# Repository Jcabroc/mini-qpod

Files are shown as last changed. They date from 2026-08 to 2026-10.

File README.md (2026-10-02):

# Mini Q-Pod

Repositorio único del Mini Q-Pod. La rama `main` es el punto de sincronización
entre los equipos de casa y oficina: no se trabaja en copias paralelas ni se
suben binarios generados o respaldos de dispositivos.

## Estado actual

| Componente | Estado | Uso |
|---|---|---|
| `mini_qpod_pico_walk_mvp/` | Activo, pendiente de validación física | Firmware Pico WH para IK y caminata lenta. |
| `mini_qpod_ik_walk_mvp/` | Referencia Nano | Misma lógica compartida; conservar para comparación. |
| `nano_servo_mapping/` | Activo de seguridad | Mapeo/calibración de un servo a la vez. |
| `tools/ik_simulator/` | Activo de ingeniería | IK/FK matemática y validación no física. |
| `tools/ik_walk_simulator/` | Activo de ingeniería | Simulador y paridad con el firmware de caminata. |
| `esp32cam/` | Diagnóstico experimental | Cámara y visión primitiva; no controla servos. |
| `mini_qpod_mvp/` | Referencia MVP | Base anterior, no punto de partida para cambios nuevos. |
| `test_gait*/`, `codigo_control_lite_v1/`, GUI y material CAD | Histórico o soporte | Consultar solo cuando la especificación lo indique. |

La fuente de verdad técnica, hardware, seguridad y estados de validación es
[ESPECIFICACION_TECNICA.md](ESPECIFICACION_TECNICA.md). Las soluciones IK y las
marchas simuladas **no** constituyen una validación física: seguir siempre los
procedimientos de seguridad de cada firmware.

La planificación oficial de la segunda etapa, sus criterios de cierre, evidencia
y sincronización entre equipos está en [docs/ROADMAP.md](docs/ROADMAP.md).
La decisión documentada para la locomoción es
[Pico WH/RP2040](docs/DECISION_LOCOMOCION.md). La ESP32-S3 SuperMini queda
reservada para sensores en una etapa posterior.

## Flujo único de trabajo

1. Actualiza antes de empezar: `git pull --ff-only origin main`.
2. Trabaja en una rama `codex/<tema>` desde `main`.
3. Ejecuta las pruebas relevantes y actualiza la especificación si cambia una
   decisión técnica.
4. Integra el resultado en `main` y vuelve a actualizar el otro equipo.

No se guardan imágenes crudas de firmware, puertos COM locales, cachés Python,
ni productos de compilación. Los respaldos privados de dispositivos se
conservan fuera del repositorio.

## Verificación sin hardware

```powershell
python -B -m unittest discover -s tools/ik_simulator -p 'test_*.py' -v
python -m unittest tools.ik_walk_simulator.test_walk tools.ik_walk_simulator.test_parity -v
python -B -m unittest discover -s tools/servo_calibrator/tests -p 'test_*.py' -v
```

Consulta los README dentro de cada componente para las dependencias y las
instrucciones de compilación.

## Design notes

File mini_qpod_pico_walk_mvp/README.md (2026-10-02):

# Mini Q-POD Pico WH Locomotion MVP

Implementación de locomoción para la Raspberry Pi Pico WH / RP2040 identificada
por serigrafía. Reutiliza una
sola biblioteca local: `libraries/MiniQpodWalkCore/`. Allí viven IK, geometría,
calibración, presets, límites y protocolo Control Lite, compartidos con el
sketch Nano de referencia. Este firmware no se ha cargado ni probado con robot.

Compilar sin cargar:

```powershell
arduino-cli compile --libraries libraries --fqbn rp2040:rp2040:rpipicow mini_qpod_pico_walk_mvp
```

La Pico inicializa el PCA9685 y el NRF24, pero arranca con los 16 PWM apagados.
READY es la única entrada que puede comenzar a escribir canales de patas;
`X` apaga de inmediato, y la pérdida de radio hace que la marcha termine en
apoyo. Los límites y los rechazos IK no se recortan ni se amplían.

GP8/GP9 quedan reservados para una UART futura con ESP32-S3 SuperMini; no se
inicializan ni implementan funciones de S3 en este firmware.

El cableado, requisitos de 3,3 V y procedimiento de banco están en
[docs/PICO_W_LOCOMOTION_BENCH.md](../docs/PICO_W_LOCOMOTION_BENCH.md).

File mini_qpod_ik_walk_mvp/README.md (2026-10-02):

# Firmware Mini Q-POD

Firmware listo para Nano ATmega328P, PCA9685 `0x40`/50 Hz y NRF24. Preserva la
geometría, montaje, calibración y límites revisados en
`328ab9302e3c5cc44ba9fedc3c6c22492ea84f03`. La marcha por cuadro está en
`ik_walk_core.h` y es la misma rutina invocada por Python.

Compila sin cargar para Nano con bootloader antiguo:

```powershell
arduino-cli compile --libraries libraries --fqbn arduino:avr:nano:cpu=atmega328old mini_qpod_ik_walk_mvp
```

El HEX ya compilado para esa placa queda en
`mini_qpod_ik_walk_mvp/build/mini_qpod_ik_walk_mvp.ino.hex`. La compilación no
lo carga al Nano.

Requiere Adafruit PWM Servo Driver y RF24. Al iniciar, todos los canales PWM
quedan apagados y CH12 (cuello) permanece apagado. READY habilita PWM en los
12 canales de patas. Los movimientos fuera de IK o de los límites calibrados
se rechazan; ante un rechazo de marcha se apaga PWM y se informa el error.

## Marcha

WALK es el preset inicial de Caminata lenta y WAVE es Onda. Ambos usan zancada
18 mm, elevación 12 mm, periodo 4 s para WALK / 2,4 s para WAVE, apoyo 0,85 y
desfases `[0, 0.5, 0.75, 0.25]`. Cada vuelo dura 15% del ciclo y el intervalo
entre vuelos 10%: hay como máximo una pata en vuelo y cuatro apoyos durante la
preparación del siguiente trípode. La rutina traslada primero el COM estimado
hacia el polígono de las tres patas que quedarán apoyadas. Conserva los puntos
de apoyo en coordenadas del suelo y usa curvas suaves para levantar, avanzar y
aterrizar.

En la primera vuelta el robot se centra sobre el primer trípode (en el modelo,
unos 9 mm de desplazamiento longitudinal y lateral); las vueltas posteriores
avanzan cerca de los 18 mm nominales por ciclo recto. El ajuste de COM deja un
margen geométrico de 2 mm al final de cada cuadro corregido en el modelo. Es
una aproximación estática, no una simulación de fuerzas ni una validación de
estabilidad física.

TROT permanece experimental. Cuando vuelan dos patas en diagonal, no se
declara estable con solo dos apoyos. PACE está fuera del selector y de los
presets del Nano.

Avance/retroceso y giro se mezclan desde los dos ejes del stick; se suavizan
aceleración, dirección y parada. Al centrar el stick, pulsar CIRCLE o mandar
`STOP`/`PAUSE`, el Nano termina el cuadro de marcha hasta que las cuatro patas
estén apoyadas. `SELECT` o `X` hacen apagado PWM inmediato. `START`/`READY`
solicitan READY; si la marcha está activa espera a detenerse antes de volver a
READY.

Con READY terminado, `STEP 0` a `STEP 3` realiza un vuelo individual coordinado
de L1, R1, L2 o R2. Usa la marcha compartida, prepara el COM sobre las otras
tres patas, detiene el avance al iniciar el vuelo y conserva sus apoyos. Se
puede ejecutar por USB serial; no es un movimiento solo de la interfaz.

La altura corporal cambia suavemente manteniendo los pies de apoyo fijos en el
suelo. La apertura se aplica progresivamente en cada aterrizaje; no reinicia
la fase ni arrastra las patas plantadas. Control Lite: TRIANGLE/CROSS cambian
altura objetivo ±4 mm; SQUARE/R3 cambian apertura objetivo ±3 mm. Los comandos
USB `HEIGHT mm` (−12..12) y `OPENING mm` (0..12) permiten ajustar los mismos
objetivos durante la marcha. Valores fuera de rango se rechazan, nunca se
recortan. Altura y apertura cambian el objetivo IK y pueden parar la marcha si
una articulación llega a un límite configurado.

## Transferir presets y Control Lite

`gait_presets.h` se genera desde
`tools/ik_walk_simulator/gait_defaults.json` con:

```powershell
python -m tools.ik_walk_simulator.export_firmware_presets
```

Tras exportar, vuelve a compilar. La interfaz muestra por separado zancada
nominal, recorrido mundial del pie y avance corporal medido. No amplíes los
límites para forzar recorrido. Por ejemplo, la configuración anterior de
50 mm pedía R1/CH3 a ~94,97° con mínimo 95° y se detenía sin recortar.

El receptor coincide con `codigo_control_lite_v1`: paquete binario PS2J de 9
bytes, canal 76, 250 kbps, dirección `JR001` y payload fijo RF24 de 32 bytes.
El emisor escribe 9 bytes; la radio rellena el tamaño fijo y `RF24::read`
consume el resto al copiar los 9 campos. No usa comandos de texto por radio ni
payload dinámico. Solo el modo 3 posiciones `mode3=2` habilita los ejes.
El transmisor filtra y centra el stick, y el receptor aplica zona muerta 0,18
sin descartar combinaciones de avance y giro. El failsafe de 500 ms al perder
paquetes centra gradualmente ambos ejes y finaliza en apoyo.

## Prueba suspendida futura

No se ha abierto ningún puerto, cargado firmware ni enviado movimiento.
Para una prueba posterior, asegura el cuerpo a un soporte rígido con patas
libres, deja a mano la desconexión de alimentación y revisa juntas/cableado sin
energía. Compila con `atmega328old`, enciende sin iniciar marcha y solicita
READY de forma deliberada. Prueba WALK primero con una entrada breve; observa
que no se solapen vuelos y que no aparezcan errores IK/límite. Verifica CIRCLE
como parada gradual y SELECT como apagado PWM. Repite WAVE; ensaya retroceso y
altura/apertura en incrementos pequeños porque los límites de R1/CH3 siguen
vigentes. Desenergiza antes de tocar el mecanismo. La estimación COM no valida
el contacto dinámico ni sustituye esta comprobación suspendida.

La paridad ejecutable es:

```powershell
python -m unittest tools.ik_walk_simulator.test_walk tools.ik_walk_simulator.test_parity -v
```

Compara objetivos READY, ángulos mecánicos/comandos eléctricos, ciclos completos
cuadro a cuadro, cambios de dirección, altura/apertura, apoyos, avance, COM y
paquete Control Lite.

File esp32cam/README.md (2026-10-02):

# ESP32-CAM USB camera diagnostic

Hardware: ESP32-D0WD-V3 rev 3.1, 4 MB flash, ESP32-CAM-MB CH340,
OV2640 camera using the AI Thinker pin mapping.

Windows serial port: COM25. Working CH340 driver: 3.7.2022.1.

Build with `./build-test.ps1`. ESP-IDF 5.4.4 is installed at
`C:/Espressif/v5.4.4/esp-idf`. Sources are copied to an ASCII-only path
because the installed Kconfig tooling mishandles the accented user path.
Camera driver commit: ee087821fb6da4dc9f294747e61c936a7169c9a7.

The test initializes PSRAM and OV2640, warms up exposure, then sends a VGA
JPEG as hexadecimal text every five seconds over the 115200-baud UART.
It does not configure Wi-Fi. Run `capture.py` using the Espressif Python
environment to save one frame under `results/`.

The original firmware backup is deliberately **not** part of this repository:
raw device images can contain saved configuration. Keep it in a private local
location after a successful read, and restore only from that private copy.
Test binaries are under `firmware/`.

Flash test (after a successful backup), with `python -m esptool`:

```
--port COM25 --baud 115200 write_flash --flash_mode dio --flash_freq 40m --flash_size 4MB 0x1000 firmware/bootloader.bin 0x8000 firmware/partition-table.bin 0x10000 firmware/cam_usb_test.bin
```

Restore an original only from its private local location with
`python -m esptool --port COM25 --baud 115200 write_flash 0 RUTA_PRIVADA_AL_RESPALDO.bin`.

Validated on 2026-09-22: full original backup verified by device MD5; test flash verified; PSRAM 8388608 bytes; OV2640 PID 0x26 initialized successfully; captured and visually inspected a 640x480 JPEG in results/camera.jpg.

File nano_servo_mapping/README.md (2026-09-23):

# Mini Q-POD Servo Mapping 1.0.0

Firmware independiente para medir el mapeo eléctrico → mecánico, sin IK,
movimientos colectivos, balance ni acceso a EEPROM. No sustituye ni modifica
`mini_qpod_mvp`. No se ha cargado ni probado físicamente.

## Cableado revisado antes de implementar

Según `mini_qpod_mvp/robot_config.h`, `gait_balance.h` y
`mini_qpod_pico_imu/mini_qpod_pico_imu.ino`:

| Función | Nano | Conexión |
|---|---|---|
| Host 115200 baud | UART USB D0/D1 | USB; no conectar la Pico aquí |
| IMU 38400 baud | D2 RX SoftwareSerial | Pico GP4 TX y GND común |
| TX ficticio SoftwareSerial | D8 | **Sin conexión física** |
| PCA9685 dirección 0x40 | A4 SDA / A5 SCL | I²C, lógica y GND común |
| LED | D5 | Encendido al enviar PWM individual |
| Buzzer | D4 | LOW, sin tonos |

No usar D3 → GP5 directamente: 5 V del Nano no son adecuados para la Pico.
Esta revisión verifica el pinout registrado, no el cableado físico presente.
No se añade un pin OE: no consta una conexión existente. La alimentación de
servos debe poder desconectarse físicamente, también durante reset/carga.
Mejora futura obligatoria: conectar `OE` del PCA9685 a un GPIO del Nano con
pull-up, de forma que las salidas permanezcan deshabilitadas durante arranque,
reinicio o fallo del Nano.

## Configuración RAM y significado de los ángulos

La siguiente tabla reproduce el `CONFIG` activo comunicado por el usuario,
no los defaults compilados del MVP ni una lectura nueva de EEPROM.
Margen global 5°; extremos seguros inclusivos.

| CH | Articulación | Mín / centro / máx eléctricos | Dirección histórica | Intervalo con margen |
|---|---|---|---|---|
| 0 | L1 COXA | 20 / 90 / 115 | +1 | 25–110 |
| 1 | L1 FÉMUR | 10 / 110 / 180 | +1 | 15–175 |
| 2 | L1 TIBIA | 25 / 90 / 180 | −1 | 30–175 |
| 3 | R1 COXA | 90 / 110 / 180 | +1 | 95–175 |
| 4 | R1 FÉMUR | 10 / 90 / 180 | −1 | 15–175 |
| 5 | R1 TIBIA | 0 / 90 / 170 | −1 | 5–165 |
| 6 | L2 COXA | 70 / 100 / 180 | +1 | 75–175 |
| 7 | L2 FÉMUR | 10 / 90 / 180 | +1 | 15–175 |
| 8 | L2 TIBIA | 0 / 100 / 160 | −1 | 5–155 |
| 9 | R2 COXA | 30 / 100 / 140 | −1 | 35–135 |
| 10 | R2 FÉMUR | 10 / 105 / 175 | −1 | 15–170 |
| 11 | R2 TIBIA | 40 / 115 / 180 | −1 | 45–175 |
| 12 | Cuello | 75 / 95 / 120 | +1 | 80–115 |

`ARM`/`MOVE` reciben grados **eléctricos absolutos**. No aplican dirección,
offset ni centro a la entrada: las direcciones se conservan como evidencia,
pendiente su correspondencia con las convenciones IK. Los intervalos con margen
son límites de software heredados, no una certificación de ausencia de colisiones.

Los centros físicos históricos CH0–CH11 son, por separado:
1505, 1700, 1590, 1645, 1555, 1635, 1690, 1635, 1565, 1590, 1600, 1725 µs.
No se convierten en centros eléctricos nuevos. La READY histórica (COXA
L1 −6°, R1 −8°, L2 +8°, R2 +6°, fémures 0°, tibias −10°) tiene una convención
todavía sin reconciliar con la IK y no se implementa aquí.

Conversión explícita, compatible con el redondeo y mapa del código MVP local:

```
a = trunc(deg + 0.5)                         # entradas válidas positivas
cuentas = 110 + trunc(a * 400 / 180)        # entero largo, no clamp
us_nominal = cuentas * (prescale + 1) / 25  # oscilador nominal 25 MHz
```

Se configura 50 Hz; se informa el prescaler leído del dispositivo, normalmente
121. Con él, 90° → 310 cuentas → 1512.80 µs nominales. No es una medición
del oscilador ni del pulso real. La rampa interna es de 10°/s, pasos máximos
0.2° cada 20 ms; la salida se cuantiza a grados enteros y cuentas. No se
promete velocidad física exacta del eje. Un bucle retrasado no recupera tiempo
con un salto grande. No se calcula trigonometría ni se duplica la IK.

## Protocolo

ASCII, mayúsculas, 115200 baud, líneas terminadas en LF (CRLF admitido).
Máximo 79 caracteres; líneas largas o corruptas se descartan completas.
Decimales con punto, sin exponentes, NaN ni infinito; número exacto de argumentos.
`X` es además un byte de emergencia inmediato, aun dentro de una línea incompleta.
No enviar varios comandos de movimiento en lote.

| Orden | Efecto |
|---|---|
| HELP | Enumera exclusivamente este protocolo y códigos |
| STATUS | Estado PWM, selección, canal activo, objetivo/salida, IMU, watchdog, último aborto |
| CONFIG | Tabla RAM con centro, conversión nominal, dirección y margen |
| IMU | Frescura, roll/pitch, edad y umbrales |
| SELECT ch | Apaga los 13 canales y selecciona uno; **no envía PWM activo** |
| ARM ch deg | Primera activación explícita: exige selección, IMU saludable y rango seguro |
| MOVE ch deg | Cambia el objetivo del único canal ya armado; rampa 10°/s |
| PING | Renueva heartbeat; nunca activa ni mueve |
| OFF | FULL_OFF en los 13 canales, elimina selección y armado |
| X | Igual apagado; no necesita LF |

`ARM` repetido se rechaza. `MOVE` antes de `ARM` se rechaza. Errores de sintaxis,
canal o rango conservan el objetivo y la salida anteriores, salvo que venza una
protección independiente: entonces se apaga. No hay recorte silencioso.
Después de OFF/aborto se requieren nueva selección y nuevo ARM; PING no rearma.

Cada respuesta tiene un sobre:
`REPLY cmd=... ch=... result=... accepted=... counts=... us_nominal=...`.
`ch=-1` y `NA` significan que no existe canal/ángulo aplicable; en un rechazo
`accepted=NA` significa que no se aceptó ningún ángulo nuevo. STATUS identifica
la salida conservada. CONFIG y STATUS/IMU/HELP añaden líneas de detalle al sobre.
CONFIG informa centros de referencia, **no** una aceptación para energizarlos.
El arranque emite nombre, versión y `build=local-fecha-hora` de compilación.

Resultados: 0 OK; 1 sintaxis; 2 canal; 3 no seleccionado; 4 ya armado;
5 no armado; 6 rango; 7 IMU; 8 bus I²C.
Abortos: 0 ninguno; 1 pérdida IMU; 2 inclinación; 3 watchdog host; 4 bus I²C.
La causa del último aborto se conserva incluso tras OFF o un nuevo ARM.
El fallo de bus queda bloqueado hasta reinicio; consultas y OFF siguen disponibles.

## Protecciones y límites de esta fase

Al arrancar se solicita FULL_OFF en los 13 canales antes y después de configurar
la frecuencia. SELECT también apaga todos; ARM vuelve a hacerlo antes del primer
pulso individual. Los canales restantes no sostienen ninguna postura.

IMU: `IMU,secuencia,roll,pitch*XX`, XOR hexadecimal del texto anterior al asterisco.
Solo tramas completas con checksum correcto, valores finitos y secuencia distinta
renuevan frescura. Se admite vuelta del contador de 16 bits; duplicados no renuevan.
Se ignora telemetría SENSOR. Edad **menor de 250 ms** y roll/pitch dentro de
±12° son obligatorios. A 250 ms sin trama o inclinación excesiva: apagado.
El watchdog de host apaga a **1000 ms** desde ARM o el último PING; MOVE y las
consultas no lo renuevan. El host debe enviar PING cada 200 ms mientras esté armado.
Las comparaciones de tiempo admiten el desbordamiento de millis().

No hay esperas de movimiento; las UART se atienden con lotes limitados. Apagado
significa envío de FULL_OFF en el mismo servicio de seguridad/comando, sujeto a
latencia UART/I²C. Wire tiene timeout de 3 ms por transacción. No es un circuito
de parada independiente: un bus averiado, MCU bloqueado o PCA que conserve estado
durante un reset puede impedir el apagado físico. Ante fallo I²C se intenta
apagar todo y se bloquea ARM, pero el estado físico no puede certificarse.

**ARM aplica inmediatamente el ángulo eléctrico solicitado.** Sin realimentación
de posición no existe punto inicial conocido para una rampa desde reposo. Suspender
el robot no elimina choques entre piezas. Confirmar físicamente un ángulo inicial
antes de ARM, disponer de corte de alimentación y no recorrer extremos a ciegas.
La rampa conservadora solo se aplica a MOVE después del primer pulso.

## Compilar y probar sin hardware

Dependencias: Arduino AVR Boards 1.8.6, Adafruit PWM Servo Driver Library 3.0.2
y Adafruit BusIO. Host: Python y `ziglang` (validado con 0.16.0).

```powershell
python -m pip install ziglang
& ./nano_servo_mapping/tests/run.ps1
arduino-cli compile --fqbn arduino:avr:nano:cpu=atmega328old nano_servo_mapping
python -B -m unittest discover -s tools/ik_simulator -p 'test_*.py' -v
python -B -m unittest discover -s tools/ik_pose_lab -p 'test_*.py' -v
python -B -m unittest discover -s tools/servo_calibrator/tests -p 'test_*.py' -v
python -B -m unittest discover -s esp32cam/tools/primitive-vision-monitor -p 'test_*.py' -v
git diff --check
```

Las pruebas C++ ejecutan el mismo parser, recepción IMU, límites y controlador
usado en AVR con un PCA simulado; no abren puertos. El ejecutable temporal se
crea fuera del repositorio. No prueban señales, cableado ni latencia física.

## Procedimiento futuro de carga y primera medición (no ejecutado)

1. Cortar físicamente la fuente de servos; robot suspendido y articulaciones
   apoyadas para que los doce canales apagados no provoquen una caída.
   Verificar el pinout anterior, masas, orientación IMU y corte accesible.
2. Tras revisar y autorizar esta versión, compilar y cargar por bootloader USB
   **solo el sketch nano_servo_mapping**, con placa Nano / ATmega328P Old Bootloader.
   Comando de referencia, sustituyendo el puerto confirmado:
   `arduino-cli upload -p COM_CONFIRMADO --fqbn arduino:avr:nano:cpu=atmega328old nano_servo_mapping`.
   No usar programador ISP, borrado de chip ni modificar fuses. Este sketch no
   incluye EEPROM.h ni accede a EEPROM. La conservación al cargar depende también
   del método de carga; el procedimiento usa bootloader, no borrado por ISP.
3. Con potencia aún desconectada, abrir 115200, verificar nombre/versión/build,
   HELP/CONFIG/STATUS/IMU. Debe indicar OFF, selected=-1, energized=-1,
   sin FATAL; verificar IMU saludable repetidamente. No continuar si falla.
4. Iniciar heartbeat PING cada 200 ms con un host que no envíe nada más
   automáticamente. El calibrador antiguo no se presume compatible con este protocolo.
   Enviar SELECT 0 y comprobar OFF y selected=0. Con instrumentos, confirmar que
   los otros doce canales carecen de pulsos antes de alimentar servos. Detenerse aquí
   y solicitar autorización explícita antes de enviar cualquier `ARM`.
5. Para CH0, 90° es el centro eléctrico registrado, no un centro mecánico aprobado.
   Confirmar que es una primera posición físicamente admisible; si no puede
   asegurarse, desacoplar la carga mecánica y establecer una referencia antes de
   energizar. Solo entonces conectar potencia y enviar ARM 0 90 explícitamente.
   Comparar respuesta (310 cuentas, µs según prescaler) y STATUS; verificar que
   solo CH0 está energizado. Cortar potencia ante cualquier anomalía.
6. Registrar yaw mecánico respecto de la referencia radial nominal de L1
   (+135° global, +X derecha, +Y frontal), junto a grados eléctricos, cuentas,
   pulso medido si disponible y sentido observado. No asumir que dirección +1
   prueba el signo de IK. Con espacio comprobado, MOVE 0 91, esperar llegada
   manteniendo PING, medir; MOVE 0 90 y medir retorno. OFF y verificar apagado.
   La dirección opuesta solo tras comprobar separación física. No buscar topes.
7. Antes de ampliar mediciones, comprobar corte por ausencia de PING, pérdida de
   IMU y OFF/X con carga desacoplada o potencia desconectada e instrumento sobre
   PWM. Comprobar todos los canales inactivos tras cada aborto. No inclinar el
   robot suspendido con servos cargados para ensayar el umbral.
8. CH1 y CH2 requieren referencias de fémur horizontal y ángulo relativo de
   tibia, medidas individualmente mediante SELECT y nuevo ARM. No energizar la
   pata completa. Guardar mediciones externamente; este firmware no las persiste.

El resultado pendiente es una tabla medida por canal que permita reconciliar
centro, offset y signo con la IK; no se implementa aún ese puente ni una marcha.

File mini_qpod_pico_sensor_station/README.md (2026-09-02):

# Mini Q-POD Pico Sensor Station

Firmware para **Raspberry Pi Pico W** que publica los sensores en el USB serie a
115200 baud para la aplicación `Mini-QPOD-Sensor-Station.exe`; conserva además
la trama IMU y retransmite todos los sensores hacia el Nano por GP4 → D2 a
38400 baud. El MVP actualizado del Nano reenvía estas tramas por su USB a
115200 baud.

## Pinout

| Periférico | Pico W |
|---|---|
| MPU6050 SDA / SCL | GP0 / GP1 |
| Sonar HC-SR04 TRIG / ECHO | GP2 / GP3 |
| DHT | GP6 |
| Impacto | GP7 |
| Touch | GP9 |
| Mini PIR | GP10 |
| LDR izquierda / derecha | GP26 ADC0 / GP27 ADC1 |
| RGB | GP13 / GP14 / GP15 — reservado, no se activa |

## Seguridad y carga

1. El ECHO del HC-SR04 **debe** pasar por divisor 5 V → 3.3 V antes de GP3.
2. El firmware inicia intentando DHT11 y alterna automáticamente DHT11/DHT22
   si no obtiene respuesta. Cuando detecte uno, lo informa por USB. Si no
   detecta ninguno, revise alimentación, GND, cable DATA y el pull-up.
3. El módulo de impacto conectado fue observado activo en alto en reposo, por
   eso `IMPACT_ACTIVE_LOW` está en `true`. Si una prueba física demuestra lo
   contrario, vuelva a cambiarlo.
4. Este sketch no controla el RGB ni el buzzer: el tipo de LED aún no está
   confirmado y el buzzer pertenece al Nano D4.
5. Conecte la aplicación al **COM USB de la Pico**, no al Nano, para ver todos
   estos datos. El Nano MVP actual solo recibe la IMU.

Compile con:

```powershell
arduino-cli compile --fqbn rp2040:rp2040:rpipicow .
```

La telemetría usa líneas `SENSOR,<sensor>,<valor>`; por ejemplo
`SENSOR,dht,23.4,58.0` y `SENSOR,ldr,512,490`.

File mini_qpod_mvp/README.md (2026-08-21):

# Mini Q-Pod MVP

Firmware mínimo, estructurado y seguro para calibrar los 13 servos del Mini
Q-Pod, probar cada pata y ejecutar una primera marcha lenta. Este MVP no incluye
cinemática inversa.

La fuente de verdad técnica del robot es
[`../ESPECIFICACION_TECNICA.md`](../ESPECIFICACION_TECNICA.md). Este README explica
el uso práctico; cualquier cambio de hardware, límites, protocolo, seguridad o
arquitectura también debe registrarse en la especificación técnica.

> **Advertencia:** los límites iniciales provienen del proyecto anterior y no
> sustituyen una calibración física. Las primeras pruebas deben hacerse con el
> robot elevado, sin peso sobre las patas y con acceso inmediato a la energía.

## Archivos

- `mini_qpod_mvp.ino`: programa principal, consola y modos.
- `robot_config.h`: único archivo de configuración habitual.
- `servo_control.h`: límites, EEPROM, movimiento suave y PCA9685.
- `gait_balance.h`: postura, marcha y receptor UART de orientación desde la Pico.
- `../mini_qpod_pico_imu/mini_qpod_pico_imu.ino`: lectura de la MPU6050 en la Pico W.

Toda orden termina en `ServoController`, que recorta ángulos al rango seguro y
limita la velocidad antes de escribir en el PCA9685.

## Hardware y dependencias

- Arduino Nano o compatible (el firmware parte del hardware actual).
- PCA9685 en dirección I²C `0x40`.
- 13 servos en canales 0 a 12.
- Biblioteca Arduino `Adafruit PWM Servo Driver Library`.
- `Wire` y `EEPROM`, incluidas con el core de Arduino AVR.
- Raspberry Pi Pico W conectada por UART al Nano.
- MPU6050 en `0x68`, conectada por I2C a la Pico W.

La fuente de los servos debe ser externa, adecuada a su consumo y compartir GND
con Arduino. No alimente los 13 servos desde el pin de 5 V del Nano.

## Instalación

1. Abra `mini_qpod_mvp/mini_qpod_mvp.ino` en Arduino IDE.
2. Instale **Adafruit PWM Servo Driver Library** desde el gestor de bibliotecas.
3. Seleccione la placa y el procesador correctos del Nano.
4. Revise `robot_config.h`, especialmente canales y límites iniciales.
5. Compile y cargue el sketch.
6. Abra Monitor Serial a **115200 baud**, terminación “Nueva línea”.

El arranque siempre deja los servos apagados. Escriba `HELP` para ver comandos.

## Secuencia obligatoria de puesta en marcha

### 1. Inspección sin energía de servos

- Confirme canal y articulación de cada servo.
- Confirme que las patas pueden moverse sin cables atrapados.
- Eleve el robot para que ninguna pata soporte peso.
- Tenga preparada la desconexión de la fuente de servos.

### 2. Entrada segura a calibración

Antes de alimentar los servos, compruebe que `IMU` informa `healthy=1`. Ejecute:

```text
CALIB
```

`CALIB` entra al modo de calibración con todos los PWM apagados. Después elija
explícitamente un canal; `SELECT` apaga primero cualquier canal que estuviera
habilitado y no produce PWM:

```text
SELECT 0
```

Solo `ENABLE` escribe el primer PWM, por lo que puede mover el servo de inmediato
desde su posición sin energía. Indique un ángulo inicial deliberado y mantenga
acceso a `OFF` y al corte de fuente:

```text
ENABLE 0 90
```

Durante calibración se habilita como máximo un canal. La pérdida de IMU aborta y
apaga los PWM. Por defecto, una inclinación mayor a 12° también aborta incluso si
el robot está elevado; `CALIBRATION_ABORT_ON_TILT` en `robot_config.h` documenta
y hace configurable esa política.

Con un canal habilitado, la aplicación debe enviar `PING` válido al menos cada
segundo. El calibrador provisional lo hace cada 250 ms. Si transcurre más de
`CALIBRATION_HOST_TIMEOUT_MS` (1000 ms) sin `PING` ni un comando válido de
calibración, el Nano apaga todos los PWM, limpia el canal seleccionado y vuelve a
`SAFE_OFF` con `[ABORT] HOST_TIMEOUT`. Un nuevo enlace nunca reactiva servos:
requiere otra vez `CALIB`, `SELECT` y `ENABLE`.

### 3. Calibración de cada servo

Mueva un servo a la vez con incrementos pequeños:

```text
SERVO 0 88
CENTER 0
```

Después de encontrar valores seguros, registre mínimo, centro y máximo:

```text
LIMITS 0 50 90 150
```

La condición obligatoria es `min < center < max`. El firmware añade un margen
interno de 5 grados a cada extremo. Repita para los canales 0 a 12 y revise:

```text
CONFIG
```

`LIMITS` exige que el PWM esté apagado. Ejecute `SELECT` (que apaga el canal),
ajuste los valores y vuelva a habilitar explícitamente el canal para probarlos.
Guarde solamente después de probar todos los canales y apagar los PWM:

```text
OFF
SAVE
```

`LOAD` recupera EEPROM únicamente en `OFF`. `DEFAULTS`, permitido solo en `OFF`, recupera los valores
compilados en `robot_config.h`; después hay que probarlos antes de ejecutar
`SAVE`.

### 4. Postura de pie

Apoye el robot en una superficie despejada y antideslizante:

```text
STAND
```

Verifique que ninguna articulación sature o fuerce la estructura. Si la postura
no es correcta, use `OFF`, vuelva a calibración y ajuste los límites o los valores
`DEFAULT_STAND_*` en `robot_config.h`.

### 5. Prueba individual de patas

Desde `STAND`, pruebe una sola pata y espere a que termine:

```text
LEG 0
LEG 1
LEG 2
LEG 3
```

Orden de nombres: `0=L1`, `1=R1`, `2=L2`, `3=R2`. Cada prueba desplaza primero
el cuerpo, levanta la pata, la adelanta, la baja y vuelve a postura estable.

No continúe si el cuerpo vuelca, una pata se arrastra, un servo alcanza el choque
o la fuente se reinicia.

### 6. Primera marcha

Solo después de superar las cuatro pruebas:

```text
STAND
UNLOCK_WALK
WALK
```

`UNLOCK_WALK` dura hasta reiniciar. La marcha usa el orden L1, R2, R1, L2 y una
sola pata elevada. Para detenerla:

```text
OFF
```

## IMU y balance

La MPU6050 no se conecta al Nano. La Pico W la lee por I2C, calcula roll/pitch
y envía una trama cada 20 ms al Nano. El cableado registrado es:

| Señal | Pico W | Nano |
|---|---:|---:|
| I2C SDA MPU6050 | GP0 | -- |
| I2C SCL MPU6050 | GP1 | -- |
| UART Pico TX -> Nano RX | GP4 | D2 |
| UART Nano TX -> Pico RX | GP5 | D3 (desconectar en este MVP) |
| Referencia eléctrica | GND | GND |

Ambos firmwares usan UART a 38400 baud. El formato es
`IMU,<secuencia>,<roll>,<pitch>*<CRC>`, donde CRC es el XOR de los bytes previos
al asterisco. Cargue primero `mini_qpod_pico_imu.ino` en la Pico y luego el MVP
en el Nano. Con el robot inmóvil y nivelado, ejecute `IMU` e incline manualmente
el cuerpo para comprobar ejes y signos antes de probar las patas.

La conexión usada por este MVP es unidireccional: GP4 de la Pico (3.3 V) puede
entrar a D2 del Nano. No conecte D3 del Nano directamente a GP5: la salida de 5 V
del Nano requiere adaptación de nivel antes de entrar a la Pico. El firmware del
Nano deja esa transmisión deshabilitada.

Con la IMU activa, una lectura inválida o inclinación superior a 12 grados aborta
el movimiento. También aborta si el Nano no recibe una trama válida durante 250
ms. La corrección de balance está limitada a 4 grados y también pasa por los
límites mecánicos.

La IMU estima inclinación; no mide directamente el centro de gravedad. El ajuste
real del soporte se realiza mediante `DEFAULT_BODY_SHIFT_GAIN` y debe validarse
físicamente para cada pata.

## Parámetros que se pueden ajustar

Mantenga pocos cambios por prueba:

- `DEFAULT_SERVOS`: límites y centros físicos.
- `DEFAULT_SAFETY_MARGIN_DEG`: margen contra choque.
- `DEFAULT_MAX_SPEED_DEG_S`: velocidad máxima.
- `DEFAULT_STAND_COXA_GAIN` y `DEFAULT_STAND_HEIGHT_GAIN`: postura.
- `DEFAULT_STEP_GAIN`: longitud articular del paso.
- `DEFAULT_LIFT_GAIN`: elevación.
- `DEFAULT_BODY_SHIFT_GAIN`: traslado previo del cuerpo.
- Tiempos `DEFAULT_*_MS`: duración de cada fase.
- Parámetros `DEFAULT_*TILT*` y `DEFAULT_BALANCE_*`: seguridad de IMU.

Cambiar los valores compilados no reemplaza automáticamente una configuración ya
guardada en EEPROM. Use `OFF`, `DEFAULTS`, repita las pruebas y finalmente `SAVE`.

## Criterio de aprobación del MVP

El firmware puede considerarse listo para continuar cuando:

1. Los 13 canales están identificados y calibrados.
2. Reiniciar conserva una configuración válida.
3. `CENTER` y `STAND` no producen choques.
4. Cada `LEG 0..3` completa diez ciclos sin pérdida de estabilidad.
5. `OFF` detiene cualquier prueba.
6. Con IMU activa, inclinación excesiva detiene la prueba.
7. La marcha completa varios ciclos lentos sin alcanzar límites.

El paso siguiente será corregir la geometría del desplazamiento de cuerpo usando
las medidas reales del robot y, una vez estable, introducir cinemática inversa.

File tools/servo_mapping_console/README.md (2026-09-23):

# Consola Mini Q-POD Servo Mapping

Cliente mínimo para el firmware `nano_servo_mapping`. Usa `pyserial`, siempre
envía líneas terminadas en LF y mantiene `PING` cada 250 ms mediante un bloqueo
de escritura compartido. El registro se guarda por defecto en
`local_backups/servo_mapping_console.log`, fuera del control de versiones.

```powershell
python -m pip install pyserial
python tools/servo_mapping_console/console.py --port COM9 --baud 115200
```

Al conectar espera el arranque y consulta `STATUS`, `IMU` y `CONFIG`. Solo
acepta `HELP`, `STATUS`, `CONFIG`, `IMU`, `SELECT`, `ARM`, `MOVE`, `OFF` y `X`.
`X` es el apagado de emergencia; también se envía al cerrar, con Ctrl+C, ante
una excepción serial y cuando la IMU deja de estar saludable. No incluye EEPROM,
WALK, STAND, límites ni expansión.

En esta fase la consola solo permite confirmar `ARM 0 90`; exige confirmación
mostrando rango seguro, cuentas y microsegundos nominales. Después limita
`MOVE 0` a 89–91°. No reintenta ARM ni MOVE.

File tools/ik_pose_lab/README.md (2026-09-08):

# Mini Q-POD Pose Lab

Aplicación de escritorio de simulación, Python 3.10+ con Tkinter (incluido en
el instalador estándar de Python para Windows). Desde la raíz del repositorio:

```powershell
python -B -m tools.ik_pose_lab
```

También se puede ejecutar `python tools/ik_pose_lab/launch.py`.
Tres paneles simultáneos muestran superior X/Y, frontal X/Z y el plano radial
de la pata seleccionada. Cuerpo de 93 × 93 mm, colores azul/verde/violeta para
COXA/fémur/tibia, objetivos ámbar o rojos. Las proyecciones se ajustan al rango.
La altura es la distancia del origen al plano de pies Z=-altura; cuerpo siempre
nivelado (roll/pitch=0). La vista frontal superpone las patas delanteras/traseras.

Los campos numéricos recalculan al editar. Apertura es la componente lateral
nominal desde cada montaje cuando yaw=0: radio = sqrt(2)*apertura.
Avance desplaza todos los pies en +Y después del abanico simétrico COXA.
Yaw positivo abre el abanico hacia los laterales desde X_NEUTRAL; no es un
ángulo eléctrico. Tras añadir avance, el yaw resuelto puede diferir del abanico.
Rama de rodilla: -1 o +1. No se imponen límites CAD ni eléctricos.

READY (altura 80, apertura 75) y X_NEUTRAL (70,85) son ejemplos matemáticos
editables, no posturas físicas aprobadas ni presets extraídos de las vistas CAD.
Los círculos ámbar marcan regiones cualitativas de incertidumbre alrededor
de COXA, con radio COXA+FEMUR solo para visualización. Sus solapamientos no
son detección de colisión: faltan volúmenes, holguras y trayectorias CAD.

Estado por pata: OK IK acompañado de zona mecánica pendiente, inalcanzable
o singularidad. Nunca se indica aprobación física global. Ver
[restricciones](../../docs/ik_constraints.md).

Guardar escribe un JSON versionado con controles; Cargar acepta ese formato
y también exportaciones. Exportar añade objetivos corporales, ángulos mecánicos
en radianes, comprobaciones y avisos calculados mediante la IK compartida.
Al cargar se recalculan resultados, sin confiar en datos derivados exportados.

Se revisó `gui_qpod_config.py`: se reaprovecha el patrón Tk/ttk y diálogos JSON.
Sus clases mezclan calibración y transporte serial; no se importan porque
introducirían dependencias de hardware innecesarias. La IK no se duplica:
se usa `ik_simulator.validation`, y FK para los extremos; los puntos intermedios
de la cadena son únicamente geometría de dibujo.

## Pruebas

```powershell
python -B -m unittest discover -s tools/ik_simulator -p "test_*.py" -v
python -B -m unittest discover -s tools/ik_pose_lab -p "test_*.py" -v
```

## EXE portable Windows (opcional)

En un entorno de construcción con Python y PyInstaller instalado
(`python -m pip install pyinstaller`), ejecutar:

```powershell
powershell -ExecutionPolicy Bypass -File tools/ik_pose_lab/build_exe.ps1
```

Resultado: `tools/ik_pose_lab/dist/Mini-QPOD-Pose-Lab.exe`. Empaqueta Tcl/Tk
y Python en un único archivo, sin consola. Compilar en Windows para Windows.
No requiere archivos CAD al ejecutar. La construcción no instala paquetes
automáticamente; el EXE debe probarse en el equipo de destino.
No existe comunicación serial, PWM, carga a Arduino ni control físico.

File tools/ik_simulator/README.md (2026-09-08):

# IK matemática en PC

La capa separada `validation.py` ofrece `validate_target(leg, body_point,
knee_sign=-1)`: devuelve solución, estados por comprobación y avisos sin aplicar
límites CAD. Ver [restricciones y referencias CAD](../../docs/ik_constraints.md).
Los estados mecánicos, eléctricos y de colisión permanecen pendientes;
`ik_reachable` no equivale a aprobación física.

Modelo independiente en Python (biblioteca estándar), sin acceso serial ni
dependencias de Arduino. Medidas confirmadas por el usuario desde el STEP original:
chasis de 93.0 × 93.0 mm entre centros COXA; COXA=42.294 mm,
FEMUR=60.611 mm, TIBIA=88.714 mm, todas centro a centro.

Origen del cuerpo: centro geométrico; +X derecha, +Y frontal, +Z arriba.
Se asumen los cuatro ejes COXA en el plano Z=0.

| Pata | X (mm) | Y (mm) | Yaw de montaje |
|---|---:|---:|---:|
| L1 | -46.5 | +46.5 | +135° |
| R1 | +46.5 | +46.5 | +45° |
| L2 | -46.5 | -46.5 | -135° |
| R2 | +46.5 | -46.5 | -45° |

El yaw es **mecánico/radial**, medido desde +X hacia +Y alrededor de +Z.
No es un ángulo eléctrico de servo. En el marco local de cada pata, +X apunta
radialmente hacia fuera, +Y es tangencial y +Z sigue arriba.
El yaw devuelto por IK es relativo al yaw de montaje de esa pata.

La API usa mm y radianes. Femur=0 significa horizontal hacia fuera; su signo
positivo eleva la pata. Knee=0 alinea tibia y fémur; knee es el ángulo relativo
de la tibia respecto del fémur, con el mismo signo de elevación.
Se supone COXA horizontal y articulaciones fémur/tibia coplanares, sin offsets
adicionales. Estas convenciones matemáticas requieren validación antes de hardware.

Para un objetivo local (x,y,z): r=hypot(x,y), h=r-COXA,
cos(knee)=(h²+z²-FEMUR²-TIBIA²)/(2 FEMUR TIBIA),
femur=atan2(z,h)-atan2(TIBIA sin(knee), FEMUR+TIBIA cos(knee)).
Yaw=atan2(y,x). Se elige la orientación COXA hacia el objetivo; no se enumera
la solución alternativa con COXA girada 180° y alcance radial firmado negativo.

`knee_sign=-1` (predeterminado) o `+1` selecciona las dos ramas planares;
ninguna se declara físicamente segura. Se rechazan objetivos fuera del anillo
de alcance y el eje vertical COXA, donde yaw no queda determinado.
Las fronteras totalmente plegada/extendida se aceptan aunque son singulares;
no se calculan velocidades ni Jacobianos. Tolerancia de frontera: 1e-9 mm,
con recorte del coseno únicamente para redondeo numérico.

La conversión a **ángulos eléctricos por canal se hará en una capa posterior**:
centros, signos, offsets, calibración y límites no pertenecen a esta IK.
Alcanzable matemáticamente no implica ausencia de colisiones ni viabilidad física.
No se modifican sketches, EEPROM ni límites de servos.

Desde la raíz del repositorio:

```console
python -B -m unittest discover -s tools/ik_simulator -p "test_*.py" -v
```

Ejemplo en Python:

```python
from tools.ik_simulator.kinematics import inverse, forward
angles = inverse("R1", (120, 120, -80))
print(angles)  # radianes mecánicos
print(forward("R1", angles))  # recupera el objetivo en el marco del cuerpo
```

Las pruebas cubren dimensiones, ejes radiales, una solución analítica,
fronteras, errores y reconstrucción FK(IK(p)) de puntos aleatorios reproducibles
para ambas ramas y las cuatro patas. No constituyen validación física.

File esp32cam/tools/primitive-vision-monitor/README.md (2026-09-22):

# Q-POD Primitive Vision Monitor

Monitor local para Windows de la salida serie de la ESP32-CAM Stage 1. Usa Tkinter y pyserial; el parser está separado de la interfaz para poder cambiar el protocolo después.

## Ejecución

Con el entorno Python de ESP-IDF preparado:

```powershell
Set-Location tools\primitive-vision-monitor
& 'C:\Espressif\tools\python\v5.4.4\venv\Scripts\python.exe' monitor.py
```

Selecciona `COM25` (o el puerto que Windows asigne), `115200` y pulsa `CONNECT`. Al conectar, la herramienta genera un pulso de reset del ESP32-CAM-MB; el estado debe pasar de `WAITING DATA` a `RX OK` y el monitor serie debe mostrar el arranque y las líneas `MOTION`.

Prueba del parser sin hardware:

```powershell
& 'C:\Espressif\tools\python\v5.4.4\venv\Scripts\python.exe' test_parser.py
```

Las líneas desconocidas se conservan en el log, pero no afectan a la interfaz. `APPROACHING`, `RECEDING`, `CONFIDENCE`, `LIGHT` y bounding boxes quedan previstos para futuras líneas del protocolo.

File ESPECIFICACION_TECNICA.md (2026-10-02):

# Especificación técnica oficial — Mini Q-Pod

| Campo | Valor |
|---|---|
| Documento | Especificación técnica y fuente de verdad del robot |
| Proyecto | Mini Q-Pod |
| Repositorio | `https://github.com/Jcabroc/mini-qpod.git` |
| Rama oficial actual | `main` |
| Versión del documento | `0.5.0` |
| Firmware activo en desarrollo | `mini_qpod_pico_walk_mvp/mini_qpod_pico_walk_mvp.ino` |
| Estado | IK y caminata compilables, pendientes de validación física |
| Última actualización | 2026-10-02 |

> Este documento es la fuente de verdad técnica del Mini Q-Pod. Toda decisión
> que cambie hardware, conexiones, límites, seguridad, comportamiento, protocolo,
> dependencias o pruebas debe quedar registrada aquí en el mismo cambio de código.

## 1. Objetivo del sistema

Mini Q-Pod es un robot cuadrúpedo de cuatro patas, tres articulaciones por pata y
un servo adicional para el cuello. El objetivo de la versión actual es conseguir
una plataforma segura y calibrable que:

1. Controle 13 servos mediante PCA9685.
2. Respete límites mecánicos configurables por articulación.
3. Limite la velocidad antes de enviar órdenes físicas.
4. Permita calibrar y guardar parámetros sin reescribir todo el firmware.
5. Adopte una postura base reproducible.
6. Desplace el cuerpo antes de levantar una pata.
7. Pruebe individualmente las cuatro patas.
8. Ejecute una marcha lenta con una sola pata elevada.
9. Incorpore posteriormente estabilización con IMU y cinemática inversa.

La cinemática inversa no pertenece al alcance del MVP actual.

### Modelo matemático independiente en PC (2026-09-08)

`tools/ik_simulator/` contiene la IK/FK y sus pruebas independientes del firmware.
Las medidas confirmadas desde el STEP original son: separación entre centros
COXA de 93.0 mm en ancho y largo; COXA=42.294 mm, FEMUR=60.611 mm y
TIBIA=88.714 mm, centro a centro. Origen en el centro geométrico del cuerpo,
+X derecha, +Y frontal, +Z arriba; montaje COXA en Z=0 como supuesto del modelo.
Montajes (X mm, Y mm, yaw): L1=(-46.5,+46.5,+135°),
R1=(+46.5,+46.5,+45°), L2=(-46.5,-46.5,-135°), R2=(+46.5,-46.5,-45°).
El yaw es mecánico/radial alrededor de +Z, desde +X hacia +Y.
La conversión a ángulos eléctricos por canal se implementará en una capa
posterior. Este modelo no cambia EEPROM, límites ni sketches de movimiento.
Convenciones, ecuaciones, selección de ramas y comando de pruebas se documentan
en `tools/ik_simulator/README.md`; no se declara validación física.

La interpretación de referencias CAD y la separación entre geometría ideal,
calibración eléctrica, sobre mecánico y colisiones se registra en
`docs/ik_constraints.md`. `tools/ik_simulator/validation.py` agrega avisos de
fronteras singulares y comprobaciones físicas pendientes; no aplica como topes
las cotas ilustrativas CAD ni habilita movimientos físicos.

`tools/ik_pose_lab/` añade una aplicación Tkinter de escritorio que consume
esta IK/validación, con tres proyecciones simultáneas y poses JSON versionadas.
Sus presets READY y X_NEUTRAL son ejemplos matemáticos; los indicadores de
incertidumbre no son detección de colisión. No incluye transporte físico.

## 2. Política de fuente de verdad

### 2.1 Archivos oficiales

El firmware activo de movimiento se desarrolla en:

```text
mini_qpod_pico_walk_mvp/
├── mini_qpod_pico_walk_mvp.ino
├── pico_w_pins.h
└── README.md

libraries/MiniQpodWalkCore/src/
├── ik_walk_runtime.h
├── ik_walk_core.h
├── gait_presets.h
├── control_lite.h
└── ps2j_packet.h
```

Responsabilidades:

- `mini_qpod_pico_walk_mvp.ino`: entrada, radio, consola serial y coordinación Pico WH.
- `pico_w_pins.h`: mapa explícito I²C/SPI/CE/CSN y UART reservada de la Pico WH.
- `ik_walk_core.h`: geometría, límites eléctricos y marcha por cuadro.
- `gait_presets.h`: presets generados desde el simulador.
- `control_lite.h` y `ps2j_packet.h`: contrato de radio PS2J.
- `README.md`: instalación y procedimiento práctico de operación.
- `ESPECIFICACION_TECNICA.md`: requisitos, decisiones y estado técnico oficial.

`mini_qpod_ik_walk_mvp/` conserva la envoltura Nano como referencia de la misma
lógica compartida; `nano_servo_mapping/` sigue siendo el firmware oficial para
calibración segura de un canal; `mini_qpod_mvp/` queda como referencia del MVP
anterior. Ninguno debe duplicarse ni usarse como base para una marcha nueva.

### 2.4 Decisión de plataforma de locomoción (2026-10-02)

Se selecciona Raspberry Pi Pico WH/RP2040 para locomoción. Existe una envoltura
Pico que compila y reutiliza el núcleo compartido; el firmware Nano permanece
como referencia. Esta implementación no carga hardware ni modifica geometría,
calibración o límites. La justificación está en
[docs/DECISION_LOCOMOCION.md](docs/DECISION_LOCOMOCION.md) y el cableado/banco
en [docs/PICO_W_LOCOMOTION_BENCH.md](docs/PICO_W_LOCOMOTION_BENCH.md).

### 2.2 Código histórico

Los demás sketches, GUI, modelos, planillas y documentos se consideran material
histórico o de referencia hasta que una sección de este documento los declare
oficiales. No se deben copiar comportamientos históricos al firmware oficial sin
documentar su origen y validarlos nuevamente.

El sketch usado como principal referencia de comportamiento fue:

```text
qpod_mini_serial_gui_gait/qpod_mini_serial_gui_gait.ino
```

Los límites iniciales del MVP proceden de `default_config.json`, pero todavía se
clasifican como **provisionales**.

### 2.3 Regla de actualización

Un cambio de código no está técnicamente completo si afecta este documento y no
lo actualiza. Como mínimo se debe revisar:

- versión y fecha;
- tabla de hardware;
- tabla de servos;
- parámetros predeterminados;
- estados y protocolo serial;
- riesgos o supuestos;
- pruebas ejecutadas;
- historial de decisiones.

## 3. Estado de verificación

Se usan tres estados:

- **CONFIRMADO:** respaldado por código y/o inspección física.
- **PROVISIONAL:** heredado del proyecto anterior, requiere prueba física.
- **PENDIENTE:** falta información o implementación.

| Elemento | Estado | Evidencia/observación |
|---|---|---|
| Arduino Nano ATmega328P | PROVISIONAL | Firmware compilado para Nano old bootloader; confirmar placa física |
| PCA9685 `0x40` | CONFIRMADO EN CÓDIGO | Usado en firmware histórico y MVP |
| 13 servos, canales 0–12 | CONFIRMADO EN CÓDIGO | Doce articulaciones y cuello |
| Fuente externa de servos | PENDIENTE | Documentar tensión, corriente y modelo |
| NRF24L01 | HISTÓRICO | Existe en firmware anterior; fuera del MVP inicial |
| Mando PS2J | HISTÓRICO | Existe en firmware anterior; fuera del MVP inicial |
| Pico WH / RP2040 | CONFIRMADO POR USUARIO | Serigrafía física comunicada; locomoción |
| ESP32-S3 SuperMini | PENDIENTE FÍSICO | Sensores/IMU posteriores; imagen de proveedor indica ESP32-S3 FH4R2 |
| Modelo de IMU | HISTÓRICO | MPU6050 usada por la Pico antes de la transición |
| MPU6050 `0x68` | HISTÓRICO | I²C GP0/GP1 en firmware de sensores anterior |
| Límites mecánicos | PROVISIONAL | Valores heredados, faltan pruebas servo por servo |
| Postura base | PROVISIONAL | Algoritmo compilado, falta prueba física |
| Elevación individual | PROVISIONAL | Secuencia compilada, falta prueba física |
| Marcha lenta | PROVISIONAL | Secuencia compilada, bloqueada hasta pruebas |
| Balance activo | PROVISIONAL | Transporte Pico-Nano implementado; faltan validar ejes y signos |
| Cinemática inversa | PENDIENTE | Etapa posterior al MVP estable |

## 4. Hardware y conexiones

### 4.1 Controlador principal

| Propiedad | Valor actual |
|---|---|
| Plataforma de locomoción | Raspberry Pi Pico WH / RP2040 |
| Referencia de firmware | Arduino Nano / ATmega328P (sin migración física) |
| Baudrate serial | 115200 |
| Bus de servos | I²C mediante PCA9685 |
| Dirección PCA9685 | `0x40` |
| Frecuencia PWM | 50 Hz |
| Pulso lógico mínimo | 110 cuentas PCA9685 |
| Pulso lógico máximo | 510 cuentas PCA9685 |
| LED | Pin D5 |
| Buzzer | Pin D4 |

La arquitectura Nano↔Pico anterior queda como referencia histórica. La
locomoción Pico WH usa I²C GP0/GP1 para PCA9685 y SPI0 GP16–GP20 para NRF24;
GP8/GP9 quedan reservados para UART con ESP32-S3. Las conexiones, VCC lógico a
3,3 V y confirmaciones físicas requeridas están en
[docs/PICO_W_LOCOMOTION_BENCH.md](docs/PICO_W_LOCOMOTION_BENCH.md).
Toda fuente de servos sigue separada y debe compartir GND con la lógica.

Los valores de pulso son una conversión global de 0–180°. Los límites de cada
articulación se aplican antes de esta conversión.

### 4.2 Alimentación

Los servos deben usar una fuente externa dimensionada para la corriente conjunta.
Arduino, PCA9685 y fuente de servos deben compartir GND. Está prohibido alimentar
los 13 servos desde el pin de 5 V del Nano.

Datos pendientes de registrar tras inspección física:

- modelo y tensión nominal de cada tipo de servo;
- tensión real de la fuente;
- corriente continua y máxima disponible;
- protecciones, fusible y método de desconexión;
- modelo de PCA9685 y disposición de alimentación.

### 4.3 IMU

La MPU6050 en `0x68` estaba documentada en I²C de la Pico (SDA GP0, SCL GP1)
como parte de la arquitectura histórica. La Pico WH dedica esos pines al
PCA9685; la futura ESP32-S3 asumirá sensores/IMU. No existe aún protocolo ni
implementación S3.

Antes de habilitar pruebas con movimiento debe confirmarse:

- tensión lógica y de alimentación;
- orientación física de los ejes;
- signos de roll y pitch;
- offsets en reposo.

La IMU estima inclinación y movimiento; no mide directamente el centro de gravedad.

## 5. Mapa oficial de articulaciones

Convención provisional de patas:

- `L1`: izquierda delantera.
- `R1`: derecha delantera.
- `L2`: izquierda trasera.
- `R2`: derecha trasera.

Esta orientación debe verificarse observando físicamente el robot.

| Índice | Canal | Nombre | Pata | Articulación | Mín. | Centro | Máx. | Dirección | Estado |
|---:|---:|---|---|---|---:|---:|---:|---:|---|
| 0 | 0 | L1_COXA | L1 | Coxa | 50 | 90 | 150 | +1 | PROVISIONAL |
| 1 | 1 | L1_FEMUR | L1 | Fémur | 10 | 95 | 180 | +1 | PROVISIONAL |
| 2 | 2 | L1_TIBIA | L1 | Tibia | 0 | 100 | 180 | -1 | PROVISIONAL |
| 3 | 3 | R1_COXA | R1 | Coxa | 30 | 90 | 130 | +1 | PROVISIONAL |
| 4 | 4 | R1_FEMUR | R1 | Fémur | 0 | 90 | 170 | -1 | PROVISIONAL |
| 5 | 5 | R1_TIBIA | R1 | Tibia | 0 | 90 | 180 | -1 | PROVISIONAL |
| 6 | 6 | L2_COXA | L2 | Coxa | 40 | 90 | 140 | +1 | PROVISIONAL |
| 7 | 7 | L2_FEMUR | L2 | Fémur | 10 | 100 | 180 | +1 | PROVISIONAL |
| 8 | 8 | L2_TIBIA | L2 | Tibia | 5 | 100 | 180 | -1 | PROVISIONAL |
| 9 | 9 | R2_COXA | R2 | Coxa | 50 | 90 | 130 | -1 | PROVISIONAL |
| 10 | 10 | R2_FEMUR | R2 | Fémur | 15 | 90 | 180 | -1 | PROVISIONAL |
| 11 | 11 | R2_TIBIA | R2 | Tibia | 0 | 90 | 180 | -1 | PROVISIONAL |
| 12 | 12 | CUELLO | — | Cuello | 45 | 90 | 135 | +1 | PROVISIONAL |

La columna `Dirección` está reservada para semántica articular y futura IK. El
MVP actual envía ángulos físicos calibrados y no invierte automáticamente el valor.

## 6. Configuración oficial del MVP

| Parámetro | Valor | Unidad | Estado |
|---|---:|---|---|
| Margen mecánico | 5 | grados por extremo | PROVISIONAL |
| Velocidad máxima | 35 | grados/s | PROVISIONAL |
| Periodo de actualización | 20 | ms | CONFIRMADO EN CÓDIGO |
| Ganancia coxa en postura | 0.30 | 0–1 | PROVISIONAL |
| Ganancia altura en postura | 0.60 | 0–1 | PROVISIONAL |
| Ganancia de paso | 0.20 | 0–1 | PROVISIONAL |
| Ganancia de elevación | 0.25 | 0–1 | PROVISIONAL |
| Desplazamiento del cuerpo | 0.08 | 0–1 | PROVISIONAL |
| Fase SHIFT | 500 | ms | PROVISIONAL |
| Fase LIFT | 350 | ms | PROVISIONAL |
| Fase SWING | 450 | ms | PROVISIONAL |
| Fase DROP | 350 | ms | PROVISIONAL |
| Fase SETTLE | 400 | ms | PROVISIONAL |
| Inclinación máxima | 12 | grados | PROVISIONAL |
| Ganancia balance proporcional | 0.35 | grados/grado | PROVISIONAL |
| Corrección máxima de balance | 4 | grados | PROVISIONAL |

El límite operativo efectivo es:

```text
[mínimo mecánico + margen, máximo mecánico - margen]
```

Toda orden debe pasar por `ServoController::setTarget()`. Ningún módulo nuevo
puede escribir directamente en el PCA9685 durante operación normal.

## 7. Persistencia de configuración

La EEPROM guarda:

- identificador mágico `0x514D`;
- versión de estructura `1`;
- margen de seguridad;
- configuración de los 13 servos;
- checksum de integridad.

Si la EEPROM es inválida, el firmware conserva los valores compilados. Los cambios
realizados con `LIMITS` viven en RAM hasta ejecutar `SAVE`.

Reglas:

1. No guardar límites sin probar el movimiento con el robot elevado.
2. Incrementar la versión de EEPROM cuando cambie la estructura almacenada.
3. Documentar toda migración o incompatibilidad.
4. `DEFAULTS` solo se admite con los servos apagados.

## 8. Máquina de estados

| Estado | Propósito | Entrada típica | Salida segura |
|---|---|---|---|
| `SAFE_OFF` | Servos sin PWM | Arranque, `OFF`, aborto | Permanece apagado |
| `CALIBRATION` | Ajuste individual | `CALIB` | `OFF` |
| `STAND_MODE` | Postura base | `STAND` | `OFF` |
| `LEG_TEST` | Ciclo de una pata | `LEG 0..3` | Vuelve a `STAND_MODE` |
| `WALK_MODE` | Marcha lenta | `UNLOCK_WALK`, `WALK` | `OFF` o aborto |

La marcha permanece bloqueada después de cada reinicio. `UNLOCK_WALK` solo la
habilita temporalmente y debe ejecutarse después de probar las cuatro patas.

## 9. Secuencia actual de movimiento

La marcha utiliza el orden:

```text
L1 → R2 → R1 → L2
```

Cada paso se divide en:

```text
SHIFT → LIFT → SWING → DROP → SETTLE
```

- `SHIFT`: desplaza el cuerpo hacia las tres patas de apoyo.
- `LIFT`: eleva fémur y tibia de la pata activa.
- `SWING`: adelanta la coxa manteniendo la pata elevada.
- `DROP`: baja la pata.
- `SETTLE`: espera transferencia de carga antes de continuar.

La geometría del desplazamiento es todavía heurística. Debe ajustarse mediante
pruebas físicas antes de clasificarse como confirmada.

## 10. Protocolo serial oficial

Configuración: **115200 baud**, comandos terminados en nueva línea.

| Comando | Condición | Acción |
|---|---|---|
| `HELP` | Cualquiera | Lista comandos |
| `STATUS` | Cualquiera | Modo, PWM, canal seleccionado/activo, IMU, fase y pata |
| `CONFIG` | Cualquiera | Mínimo, centro, máximo, dirección, margen y límites efectivos |
| `IMU` | Cualquiera | Salud, roll y pitch |
| `PING` | Cualquiera | Renueva la comunicación de calibración; nunca habilita ni mueve servos |
| `OFF` | Cualquiera | Detiene y desenergiza servos |
| `CALIB` | IMU segura | Entra a calibración con todos los PWM apagados |
| `SELECT <ch>` | `CALIBRATION` | Selecciona canal y apaga antes el anterior; no energiza |
| `ENABLE <ch> <deg>` | Canal seleccionado e IMU segura | Activa solo ese canal con el primer PWM explícito |
| `CENTER <ch>` | Canal seleccionado y habilitado | Lleva solo ese canal al centro efectivo |
| `SERVO <ch> <deg>` | Canal seleccionado y habilitado | Mueve solo ese canal dentro de límites seguros |
| `LIMITS <ch> <min> <center> <max>` | `CALIBRATION` | Cambia límites en RAM |
| `SAVE` | `SAFE_OFF`, configuración válida | Guarda EEPROM |
| `LOAD` | `SAFE_OFF` | Recupera EEPROM válida |
| `DEFAULTS` | `SAFE_OFF` | Restaura valores compilados en RAM |
| `STAND` | Zona despejada | Activa postura base |
| `LEG <0..3>` | `STAND_MODE` | Prueba una pata |
| `UNLOCK_WALK` | Tras pruebas | Desbloquea marcha hasta reiniciar |
| `WALK` | `STAND_MODE` y desbloqueado | Inicia marcha lenta |

## 11. Seguridad obligatoria

1. Primera calibración con el robot elevado y sin carga en las patas.
2. Acceso inmediato al corte de alimentación de servos.
3. Fuente externa de servos con GND común.
4. Un solo servo por vez durante búsqueda de límites.
5. Incrementos pequeños de ángulo cerca de extremos.
6. Nunca asumir que los valores históricos son físicamente seguros.
7. Probar `CENTER`, luego `STAND`, luego `LEG 0..3`, y solo después `WALK`.
8. No activar balance hasta validar modelo, ejes y signos de la IMU.
9. Toda salida motriz nueva debe pasar por la capa de límites.
10. Ante ruido, calentamiento, vibración, reinicio o bloqueo: cortar energía.

Con IMU activa, una lectura inválida o inclinación mayor al umbral detiene el
movimiento y apaga los servos, incluida la calibración. La inclinación durante
calibración se controla con `CALIBRATION_ABORT_ON_TILT`, que parte en `true` por
seguridad aunque el robot esté elevado. Esta protección todavía requiere
validación física.

Con un canal habilitado en `CALIBRATION`, el Nano exige comunicación válida de la
aplicación: `PING` o un comando de calibración válido deben llegar en menos de
1000 ms. Si vence ese plazo, el Nano apaga todos los PWM, limpia selección y
canal activo, entra a `SAFE_OFF` y deja `abort=HOST_TIMEOUT` enclavado en
`STATUS`. `PING` no puede habilitar ni mover un servo.

## 12. Procedimiento de validación

### 12.1 Puerta A — Electrónica

- [ ] Confirmar placa y bootloader.
- [ ] Confirmar PCA9685 y dirección.
- [ ] Documentar fuente de servos.
- [ ] Confirmar masa común.
- [ ] Confirmar canal físico de los 13 servos.

### 12.2 Puerta B — Calibración

- [ ] Calibrar mínimo, centro y máximo del canal 0.
- [ ] Calibrar canales 1–12.
- [ ] Verificar margen de 5°.
- [ ] Guardar EEPROM.
- [ ] Reiniciar y confirmar persistencia.

### 12.3 Puerta C — Postura

- [ ] `CENTER` sin choque.
- [ ] `STAND` sin choque.
- [ ] Ningún servo permanece saturado.
- [ ] Alimentación estable y sin reinicios.

### 12.4 Puerta D — Patas

- [ ] `LEG 0`: 10 ciclos.
- [ ] `LEG 1`: 10 ciclos.
- [ ] `LEG 2`: 10 ciclos.
- [ ] `LEG 3`: 10 ciclos.
- [ ] El cuerpo permanece dentro del polígono de soporte.

### 12.5 Puerta E — IMU

- [ ] Identificar modelo y orientación.
- [ ] Verificar dirección I²C.
- [ ] Calibrar offsets.
- [ ] Confirmar signos de roll y pitch.
- [ ] Confirmar parada por sensor inválido.
- [ ] Confirmar parada por inclinación excesiva.

### 12.6 Puerta F — Marcha

- [ ] Completar un ciclo lento.
- [ ] Completar 10 ciclos sin choque.
- [ ] Detener correctamente con `OFF`.
- [ ] Registrar límites alcanzados y comportamiento.
- [ ] Repetir sobre superficie real de operación.

## 13. Compilación verificada

El MVP `v0.1` fue compilado localmente para:

```text
arduino:avr:nano:cpu=atmega328old
```

Resultado registrado:

| Recurso | Uso | Disponible |
|---|---:|---:|
| Flash | 14.946 bytes (48%) | 30.720 bytes |
| RAM global | 1.007 bytes (49%) | 2.048 bytes |
| RAM restante estimada | 1.041 bytes | — |

La compilación correcta no equivale a validación física.

## 14. Requisitos antes de cinemática inversa

No se iniciará IK hasta cumplir:

1. Mapa físico confirmado.
2. Límites mecánicos confirmados.
3. Postura repetible.
4. Elevación estable de las cuatro patas.
5. IMU identificada y calibrada.
6. Convención cartesiana documentada.
7. Medidas reales de coxa, fémur y tibia.
8. Origen y orientación del sistema de coordenadas definidos.

La futura cadena de control será:

```text
objetivo de pie (x,y,z)
→ IK
→ ángulos articulares
→ validación geométrica
→ ServoController
→ límites físicos
→ PCA9685
```

## 15. Datos pendientes del robot físico

Registrar durante las próximas pruebas:

| Dato | Valor |
|---|---|
| Modelo exacto del Arduino | PENDIENTE |
| Modelo de los servos | PENDIENTE |
| Modelo de la IMU | PENDIENTE |
| Tensión/corriente de fuente | PENDIENTE |
| Longitud de coxa | PENDIENTE |
| Longitud de fémur | PENDIENTE |
| Longitud de tibia | PENDIENTE |
| Masa total | PENDIENTE |
| Posición aproximada del centro de masa | PENDIENTE |
| Orientación física de ejes IMU | PENDIENTE |

## 16. Convención de versiones

- Firmware MVP: `0.x.y` mientras no supere todas las puertas de validación.
- Firmware `1.0.0`: primera marcha estable, segura y reproducible.
- Cambios incompatibles de EEPROM deben incrementar su versión interna.
- Cada ensayo físico debe registrar fecha, firmware, configuración y resultado.

## 17. Historial de decisiones

| Fecha | Decisión | Motivo |
|---|---|---|
| 2026-08-12 | Separar el MVP en cuatro archivos de código | Mantener claridad sin fragmentar en exceso |
| 2026-08-12 | Usar `robot_config.h` como configuración habitual | Reducir puntos de ajuste |
| 2026-08-12 | Centralizar órdenes en `ServoController` | Impedir que módulos evadan límites |
| 2026-08-12 | Mantener IMU desactivada | El modelo físico no está confirmado |
| 2026-08-12 | Bloquear marcha hasta `UNLOCK_WALK` | Evitar activación accidental |
| 2026-08-12 | Posponer IK | Primero validar mecánica, postura y balance |
| 2026-08-12 | Crear esta especificación | Establecer una fuente de verdad mantenible |

## 18. Registro de pruebas

Añadir una fila por sesión física. No reemplazar resultados anteriores.

| Fecha | Firmware | Configuración | Prueba | Resultado | Observaciones |
|---|---|---|---|---|---|
| — | — | — | — | PENDIENTE | Aún no hay pruebas físicas registradas en este documento |

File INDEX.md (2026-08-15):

# 📦 Q-POD MINI - SISTEMA DE CONFIGURACIÓN
## 📋 Índice de Archivos Entregados

---

## 🎯 ¿QUÉ ACABAS DE RECIBIR?

Un **sistema completo** para parametrizar tu robot Mini Q-Pod sin recompilar código:

✅ **GUI interactiva** en Python (Tkinter)  
✅ **Comunicación serial** bidireccional con Arduino  
✅ **Almacenamiento en EEPROM** del Nano  
✅ **Guardar/cargar configuraciones** en JSON  
✅ **Monitoreo en tiempo real** de estado  

---

## 📂 ARCHIVOS PYTHON

### 1. `gui_qpod_config.py` ⭐ PRINCIPAL
**La interfaz gráfica completa**

```
Características:
├─ Tab 1: Estado (NRF24, PCA9685, servos)
├─ Tab 2: Calibración (ángulos A/Center/B)
├─ Tab 3: Posturas (ganancias standPose)
├─ Tab 4: Gait (ganancias + timings)
├─ Tab 5: Avanzado (control remoto PS2J)
├─ Tab 6: Log (terminal debug)
└─ Botones: Guardar/Cargar JSON, Enviar a EEPROM
```

**Cómo usar:**
```bash
python gui_qpod_config.py
```

---

### 2. `quickstart_config.py` 🚀 RÁPIDO
**Carga rápida sin GUI**

```
Use case:
- Cargar configuración de una vez
- Sin interfaz gráfica (útil para SSH)
- Prueba rápida de conectividad
```

**Cómo usar:**
```bash
python quickstart_config.py
```

Flujo:
1. Lista puertos COM
2. Prueba conexión
3. Carga default_config.json
4. Guarda en EEPROM

---

## 📂 ARCHIVOS DE CONFIGURACIÓN

### 3. `default_config.json`
**Valores por defecto del robot**

```json
{
  "angleA": [...],           // Ángulo extremo 1 de servos
  "angleCenter": [...],      // Centro calibrado
  "angleB": [...],           // Ángulo extremo 2
  "standPose_coxaGain": 0.45,
  "standPose_heightGain": 0.70,
  "gait_coxaGain": 0.28,
  "gait_liftGain": 0.30,
  "gait_liftMs": 150,
  "gait_swingMs": 180,
  "gait_dropMs": 150,
  "gait_pushMs": 200,
  "filter_strength": 4,
  "deadzone_percent": 6,
  "send_period_ms": 20
}
```

Puedes crear más configuraciones:
- `qpod_spider_pose.json`
- `qpod_aggressive_gait.json`
- etc.

---

## 📂 ARCHIVOS ARDUINO

### 4. `serial_protocol.cpp`
**Protocolo de comunicación serial**

Contiene:
- Estructura EEPROM
- Funciones de lectura/escritura EEPROM
- Parser de comandos serial

⚠️ Necesita ser **integrado en test_gait.ino**

---

## 📚 DOCUMENTACIÓN

### 5. `README_CONFIGURACION.md` 📖 MANUAL COMPLETO
Includes:
- Descripción del sistema
- Instalación paso a paso
- Cómo usar cada componente
- Explicación de parámetros
- Protocolo serial completo
- Estructura EEPROM
- Troubleshooting

**Lectura obligatoria** para entender el sistema

---

### 6. `INTEGRACION_PASO_A_PASO.md` 🔌 GUÍA ARDUINO
**Instrucciones exactas para integrar en test_gait.ino**

Paso a paso:
1. Añadir `#include <EEPROM.h>`
2. Copiar definiciones EEPROM
3. Copiar protocolo serial
4. Modificar `setup()` → añadir `eeprom_init()`
5. Modificar `loop()` → añadir `serial_process()`

**Con ejemplos de código exacto** que debes copiar/pegar

---

### 7. `QUICK_REFERENCE.md` ⚡ CHEAT SHEET
**Referencia rápida**

Incluye:
- Instalación rápida (3 líneas)
- 3 formas de usar
- Comandos serial rápidos
- Numeración de servos
- Parámetros recomendados
- Troubleshooting tabla
- Workflow típico

**Imprímelo o guárdalo en favoritos**

---

### 8. `INDEX.md` (este archivo)
**Descripción de todos los archivos**

---

## 🚀 INICIO RÁPIDO (ELIJE UNO)

### Opción A: 5 minutos sin Arduino (solo Python)
```bash
pip install pyserial
python quickstart_config.py
```

### Opción B: GUI completa (recomendado)
```bash
pip install pyserial
python gui_qpod_config.py
# Se abre interfaz gráfica
```

### Opción C: Integración con Arduino
1. Lee `INTEGRACION_PASO_A_PASO.md` (15 min)
2. Sigue exactamente los 5 pasos
3. Compila `test_gait.ino` con protocolo integrado
4. Luego: `python gui_qpod_config.py`

---

## 📊 WORKFLOW RECOMENDADO

```
Semana 1: Familiarización
├─ Lee QUICK_REFERENCE.md (5 min)
├─ Ejecuta quickstart_config.py (5 min)
└─ Explora GUI sin Arduino conectado (5 min)

Semana 2: Integración
├─ Lee INTEGRACION_PASO_A_PASO.md (15 min)
├─ Integra protocolo en Arduino (15 min)
├─ Compila y prueba conexión (5 min)
└─ Verifica con Monitor Serial (10 min)

Semana 3: Calibración
├─ Conecta GUI a Arduino
├─ Calibra servos uno por uno
├─ Ajusta standPose (ganancias)
├─ Guarda configuración JSON
└─ Verifica persistencia en EEPROM

Semana 4+: Optimización Gait
├─ Abre Tab "Gait" en GUI
├─ Modifica ganancias en vivo
├─ Prueba diferentes timings
├─ Perfecciona marcha del robot
└─ Guarda versiones: gait_v1.json, gait_v2.json, etc
```

---

## 🔑 PUNTOS CLAVE

### Capacidades
✅ **Sin recompilar:** Cambios en tiempo real  
✅ **Persistencia:** Los parámetros se guardan en EEPROM  
✅ **Portabilidad:** Múltiples configuraciones JSON  
✅ **Debugging:** Terminal serial en vivo  
✅ **Seguridad:** Validación de comandos  

### Limitaciones
⚠️ GUI necesita display (no SSH)  
⚠️ Baud rate: DEBE ser 115200  
⚠️ EEPROM tiene límite (~1024 bytes)  
⚠️ Sin sensores de realimentación aún  

---

## 📝 RESUMEN DE ARCHIVOS

| Archivo | Tipo | Propósito |
|---|---|---|
| gui_qpod_config.py | Python | Interfaz gráfica completa ⭐ |
| quickstart_config.py | Python | Carga rápida sin GUI |
| serial_protocol.cpp | Arduino | Protocolo serial (integrar) |
| default_config.json | JSON | Configuración por defecto |
| README_CONFIGURACION.md | Doc | Manual completo 📖 |
| INTEGRACION_PASO_A_PASO.md | Doc | Guía Arduino 🔌 |
| QUICK_REFERENCE.md | Doc | Cheat sheet ⚡ |
| INDEX.md | Doc | Este archivo |

---

## 🎓 ÓRDENES DE LECTURA RECOMENDADO

**Para empezar rápido:**
1. QUICK_REFERENCE.md (5 min)
2. Ejecuta quickstart_config.py

**Para usar la GUI:**
1. QUICK_REFERENCE.md
2. README_CONFIGURACION.md
3. Ejecuta gui_qpod_config.py

**Para integrar con Arduino:**
1. README_CONFIGURACION.md (opcional, para contexto)
2. INTEGRACION_PASO_A_PASO.md (OBLIGATORIO)
3. Integra en test_gait.ino
4. Usa GUI o quickstart

---

## 🔗 DEPENDENCIES

Python:
```
pyserial          (comunicación serial)
tkinter           (incluido en Python)
json              (incluido en Python)
threading         (incluido en Python)
```

Arduino:
```
Wire.h            (I2C, incluido)
Adafruit_PWMServoDriver.h
RF24.h            (NRF24)
EEPROM.h          (incluido)
```

---

## ✨ PRÓXIMOS PASOS SUGERIDOS

1. **Mejora de marcha:**
   - Implementar easing en movimientos
   - Detectar obstáculos
   - Adaptive gait basado en terreno

2. **Sensorización:**
   - Lectura de batería
   - Estado de PCA9685
   - Inclinómetro del robot

3. **Grabación de datos:**
   - Log de consumo
   - Historial de configuraciones
   - Análisis de rendimiento

4. **Integración Pico:**
   - Enviar datos desde Pico a Nano
   - Controlar parámetros remotamente

---

## 📞 SOPORTE

Si tienes problemas:

1. **Python no instala pyserial:**
   ```powershell
   python -m pip install pyserial
   ```

2. **Arduino no responde:**
   - Abre Monitor Serial de Arduino IDE
   - Baud rate: 115200
   - Envía comando "INFO"

3. **GUI no se abre:**
   - Necesitas display (Windows/Linux con GUI)
   - SSH no funciona (sin display)

4. **Parámetros no persisten:**
   - Verifica que usaste botón "📤 → Arduino (EEPROM)"
   - Espera a que aparezca el mensaje "✓ GUARDADO"

---

## 🎉 ¡ÉXITO!

Ahora tienes:
✅ Configuración sin recompilar  
✅ GUI amigable  
✅ Almacenamiento persistente  
✅ Sistema escalable  

**¡A calibrar el Q-POD!** 🤖

---

*Última actualización: 23 de abril de 2026*

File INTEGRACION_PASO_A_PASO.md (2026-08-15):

# 🔌 GUÍA INTEGRACIÓN - PROTOCOLO SERIAL EN test_gait.ino

## ⚠️ ANTES DE EMPEZAR
- Guarda una copia de `test_gait.ino` (backup)
- Lee esta guía COMPLETA antes de empezar
- Sigue exactamente los pasos

---

## 📋 PASO 1: Añadir INCLUDES

Abre tu archivo `test_gait.ino` y busca la sección de includes al inicio (líneas 1-10):

```cpp
#include <Wire.h>
#include <Adafruit_PWMServoDriver.h>
#include <SPI.h>
#include <nRF24L01.h>
#include <RF24.h>
#include <math.h>
```

**Añade esta línea al final de los includes:**

```cpp
#include <EEPROM.h>
```

Resultado:
```cpp
#include <Wire.h>
#include <Adafruit_PWMServoDriver.h>
#include <SPI.h>
#include <nRF24L01.h>
#include <RF24.h>
#include <math.h>
#include <EEPROM.h>    // ← NUEVA
```

---

## 📋 PASO 2: Definiciones EEPROM

Encuentra la sección donde están definidas las constantes (PWM_FREQ, SERVO_MIN, etc). 

Busca esta línea:
```cpp
const int SERVO_MAX = 510;
```

Justo **después** de esa línea, inserta TODO esto:

```cpp
// =====================================================
// EEPROM MANAGER
// =====================================================
#include <EEPROM.h>

struct EEPROMData {
  uint8_t magic;
  uint8_t angleA[13];
  uint8_t angleCenter[13];
  uint8_t angleB[13];
  float standPose_coxaGain;
  float standPose_heightGain;
  float gait_coxaGain;
  float gait_liftGain;
  uint16_t gait_liftMs;
  uint16_t gait_swingMs;
  uint16_t gait_dropMs;
  uint16_t gait_pushMs;
};

const uint16_t EEPROM_BASE = 0;
EEPROMData eepromData;

void eeprom_init() {
  EEPROM.get(EEPROM_BASE, eepromData);
  if (eepromData.magic != 0xAA) {
    Serial.println("[EEPROM] No válido, inicializando...");
    for (int i = 0; i < 13; i++) {
      eepromData.angleA[i] = angleA[i];
      eepromData.angleCenter[i] = angleCenter[i];
      eepromData.angleB[i] = angleB[i];
    }
    eepromData.standPose_coxaGain = 0.45f;
    eepromData.standPose_heightGain = 0.70f;
    eepromData.gait_coxaGain = 0.28f;
    eepromData.gait_liftGain = 0.30f;
    eepromData.gait_liftMs = GAIT_LIFT_MS;
    eepromData.gait_swingMs = GAIT_SWING_MS;
    eepromData.gait_dropMs = GAIT_DROP_MS;
    eepromData.gait_pushMs = GAIT_PUSH_MS;
    eeprom_write();
  }
  Serial.println("[EEPROM] ✓ Inicializado");
}

void eeprom_write() {
  eepromData.magic = 0xAA;
  EEPROM.put(EEPROM_BASE, eepromData);
  Serial.println("[EEPROM] ✓ Guardado");
}
```

---

## 📋 PASO 3: Protocolo Serial

Después del código de EEPROM anterior, añade esta nueva función:

```cpp
// =====================================================
// PROTOCOLO SERIAL
// =====================================================
void serial_process() {
  while (Serial.available()) {
    String line = Serial.readStringUntil('\n');
    line.trim();
    if (line.length() == 0) return;
    
    int spaceIdx = line.indexOf(' ');
    String cmd = (spaceIdx > 0) ? line.substring(0, spaceIdx) : line;
    String args = (spaceIdx > 0) ? line.substring(spaceIdx + 1) : "";
    
    // Calibración
    if (cmd == "A") {
      int ch = args.toInt();
      int angle = args.substring(args.indexOf(' ') + 1).toInt();
      if (ch >= 0 && ch <= 12) {
        angleA[ch] = angle;
        targetAngle[ch] = angle;
        Serial.print("[A] CH");
        Serial.print(ch);
        Serial.print(" = ");
        Serial.println(angle);
      }
    }
    else if (cmd == "C") {
      int ch = args.toInt();
      int angle = args.substring(args.indexOf(' ') + 1).toInt();
      if (ch >= 0 && ch <= 12) {
        angleCenter[ch] = angle;
        targetAngle[ch] = angle;
        Serial.print("[C] CH");
        Serial.print(ch);
        Serial.print(" = ");
        Serial.println(angle);
      }
    }
    else if (cmd == "B") {
      int ch = args.toInt();
      int angle = args.substring(args.indexOf(' ') + 1).toInt();
      if (ch >= 0 && ch <= 12) {
        angleB[ch] = angle;
        targetAngle[ch] = angle;
        Serial.print("[B] CH");
        Serial.print(ch);
        Serial.print(" = ");
        Serial.println(angle);
      }
    }
    
    // EEPROM
    else if (cmd == "EEPROM_A") {
      int ch = args.toInt();
      int angle = args.substring(args.indexOf(' ') + 1).toInt();
      if (ch >= 0 && ch <= 12) eepromData.angleA[ch] = angle;
    }
    else if (cmd == "EEPROM_C") {
      int ch = args.toInt();
      int angle = args.substring(args.indexOf(' ') + 1).toInt();
      if (ch >= 0 && ch <= 12) eepromData.angleCenter[ch] = angle;
    }
    else if (cmd == "EEPROM_B") {
      int ch = args.toInt();
      int angle = args.substring(args.indexOf(' ') + 1).toInt();
      if (ch >= 0 && ch <= 12) eepromData.angleB[ch] = angle;
    }
    else if (cmd == "EEPROM_SAVE") {
      eeprom_write();
      // Cargar en runtime
      for (int i = 0; i < 13; i++) {
        angleA[i] = eepromData.angleA[i];
        angleCenter[i] = eepromData.angleCenter[i];
        angleB[i] = eepromData.angleB[i];
      }
      Serial.println("[EEPROM] ✓ GUARDADO");
    }
    
    // Consultas
    else if (cmd == "STATE") {
      Serial.print("STATE: NRF=");
      Serial.print(linkAlive ? "OK" : "LOST");
      Serial.print(" PCA=OK MODE=");
      Serial.println(rxData.mode3);
    }
    else if (cmd == "ANGLES") {
      Serial.print("SERVO: ");
      for (int i = 0; i < 13; i++) {
        Serial.print(i);
        Serial.print("=");
        Serial.print((int)currentAngle[i]);
        if (i < 12) Serial.print(" ");
      }
      Serial.println();
    }
    else if (cmd == "INFO") {
      Serial.println("Q-POD MINI - Comandos:");
      Serial.println(" A/C/B <ch> <ang> - Set ángulos");
      Serial.println(" STATE - Estado");
      Serial.println(" ANGLES - Ángulos actuales");
      Serial.println(" EEPROM_SAVE - Guardar");
    }
  }
}
```

---

## 📋 PASO 4: Modificar setup()

Encuentra tu función `void setup()` y busca esta línea:

```cpp
buildPoseTables();
buildStandPose();
```

**Justo DESPUÉS de esas líneas**, añade:

```cpp
  // EEPROM
  eeprom_init();
```

Ejemplo completo (solo mostramos contexto):
```cpp
void setup() {
  pinMode(PIN_LED, OUTPUT);
  pinMode(PIN_BUZZER, OUTPUT);

  digitalWrite(PIN_LED, LOW);
  noTone(PIN_BUZZER);

  Serial.begin(115200);
  delay(600);

  Serial.println();
  Serial.println("=== Q-POD MINI RX SAFE GAIT TEST ===");

  Wire.begin();
  pca.begin();
  pca.setPWMFreq(PWM_FREQ);
  delay(100);
  allOff();
  Serial.println("PCA9685 lista.");

  buildPoseTables();
  buildStandPose();
  
  // ← AÑADE ESTA LÍNEA
  eeprom_init();
  // ← FIN AÑADIDA

  for (int ch = FIRST_CH; ch <= LAST_CH; ch++) {
    targetAngle[ch] = standPose[ch];
    currentAngle[ch] = standPose[ch];
  }
  
  // ... resto del setup ...
}
```

---

## 📋 PASO 5: Modificar loop()

Encuentra tu función `void loop()` y ve al **final** de la función, justo antes del cierre `}`.

Busca algo como esto:
```cpp
void loop() {
  if (radio.available()) {
    // ... procesamiento NRF ...
  }

  if (linkAlive && (millis() - lastPacketMs > 800)) {
    // ... timeout ...
  }

  if (millis() - lastMotionMs >= MOTION_PERIOD_MS) {
    // ... actualización de movimiento ...
  }
}  // ← El cierre de la función
```

**Justo ANTES del cierre `}` final**, añade:

```cpp
  // Procesar comandos serial
  serial_process();
```

Ejemplo:
```cpp
void loop() {
  if (radio.available()) {
    while (radio.available()) {
      radio.read(&rxData, sizeof(rxData));
    }
    // ... resto del procesamiento ...
  }

  if (linkAlive && (millis() - lastPacketMs > 800)) {
    linkAlive = false;
    digitalWrite(PIN_LED, LOW);
    prevBtn = 0;
    gaitActive = false;
    Serial.println("LINK LOST");
    beep(700, 140);
  }

  if (millis() - lastMotionMs >= MOTION_PERIOD_MS) {
    lastMotionMs = millis();
    if (servosEnabled) {
      float step = (rxData.mode3 == 0) ? SPEED_CALIB :
                   (rxData.mode3 == 1) ? SPEED_MANUAL :
                                         SPEED_GAIT;
      updateMotion(step);
    }
  }

  // ← AÑADE ESTA LÍNEA
  serial_process();
  // ← FIN AÑADIDA
}
```

---

## ✅ VERIFICACIÓN

Una vez añadido TODO, compila el código:

```
Arduino IDE → Verify (Ctrl+R)
```

Si NO hay errores → ¡ÉXITO! 🎉

Si hay errores:
- Verifica que NO duplicaste `#include <EEPROM.h>`
- Comprueba que las llaves `{}` están correctas
- Asegúrate de que copiaste EXACTAMENTE el código

---

## 🚀 PRUEBA

1. Sube el código a Arduino Nano
2. Abre PowerShell:
```powershell
cd "f:\Documentos\Jota\jRobot\mini Q-Pod"
python quickstart_config.py
```
3. Selecciona tu puerto COM
4. Cuando aparezca el menú, presiona `s` para confirmar
5. Debería ver el progreso de carga

Si todo va bien:
```
✓ ÉXITO - Puedes desenchufar y enchufar el Arduino
  Los parámetros se guardarán en EEPROM
```

---

## 🎛️ PRÓXIMO PASO

Una vez verificado que funciona:

```powershell
python gui_qpod_config.py
```

Esto abre la interfaz gráfica completa para calibración avanzada.

---

## ❓ SI ALGO FALLA

### Error: "struct EEPROMData"
**Causa:** Copiaste el código en lugar equivocado  
**Solución:** Busca exactamente dónde ir en PASO 2

### Error: "eeprom_init not defined"
**Causa:** No copiaste la función completa  
**Solución:** Verifica que toda la función esté presente

### Arduino no responde en Python
**Causa:** Falta `serial_process()` en loop()  
**Solución:** Verifica PASO 5

### Compila pero no ve cambios
**Causa:** Arduino no reinicia después de programación  
**Solución:** Desenchufa/enchúfa manualmente

---

## 💾 GUARDADO

Una vez compilado y funcionando, tu robot **recordará automáticamente** los parámetros incluso sin alimentación.

¡Éxito! 🚀

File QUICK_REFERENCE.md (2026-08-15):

# 🚀 Q-POD MINI - QUICK REFERENCE

## 📥 INSTALACIÓN RÁPIDA

```bash
# 1. Instalar Python + pyserial
pip install pyserial

# 2. En tu carpeta del proyecto
python quickstart_config.py

# 3. Cuando pregunte: cargar default_config.json

# 4. Listo ✓
```

---

## 🎯 3 FORMAS DE USAR

### Opción A: Quickstart (Carga rápida)
```bash
python quickstart_config.py
```
✅ Para cargar configuración de una sola vez  
❌ Sin interfaz visual

### Opción B: GUI Completa (Recomendado)
```bash
python gui_qpod_config.py
```
✅ Interfaz bonita y amigable  
✅ Calibración en vivo  
✅ Manejo de configs JSON  
⚠️ Requiere que tengas GUI (no funciona en SSH)

### Opción C: Manual con Monitor Serial
```
Arduino IDE → Tools → Serial Monitor
Baud: 115200
```
✅ Debugging detallado  
❌ Tedioso para muchos cambios

---

## ⚡ COMANDOS SERIAL (Todos)

```
A <ch> <angle>          → Set angleA[ch]
C <ch> <angle>          → Set angleCenter[ch]
B <ch> <angle>          → Set angleB[ch]

EEPROM_A <ch> <angle>   → Guardar angleA en EEPROM
EEPROM_C <ch> <angle>   → Guardar angleCenter en EEPROM
EEPROM_B <ch> <angle>   → Guardar angleB en EEPROM
EEPROM_SAVE             → Confirmar guardado

STATE                   → Ver estado (NRF/PCA)
ANGLES                  → Ver ángulos actuales
INFO                    → Ver este mensaje
```

---

## 📊 SERVOS (Numeración)

```
L1 = pata delantera izquierda    |  R1 = pata delantera derecha
├─ CH0: COXA                     |  ├─ CH3: COXA
├─ CH1: FEMUR                    |  ├─ CH4: FEMUR
└─ CH2: TIBIA                    |  └─ CH5: TIBIA

L2 = pata trasera izquierda      |  R2 = pata trasera derecha
├─ CH6: COXA                     |  ├─ CH9: COXA
├─ CH7: FEMUR                    |  ├─ CH10: FEMUR
└─ CH8: TIBIA                    |  └─ CH11: TIBIA

CH12 = CUELLO
```

---

## 🎚️ PARÁMETROS RECOMENDADOS

### Postura Base (standPose)
```
standPose_coxaGain      = 0.45 ± 0.10     (apertura patas)
standPose_heightGain    = 0.70 ± 0.10     (altura)
```

### Marcha (Gait)
```
gait_coxaGain           = 0.28 ± 0.10     (amplitud pasos)
gait_liftGain           = 0.30 ± 0.10     (altura levantada)

gait_liftMs             = 150              (tiempo lift)
gait_swingMs            = 180              (tiempo swing)
gait_dropMs             = 150              (tiempo drop)
gait_pushMs             = 200              (tiempo push)
```

---

## 📁 ARCHIVOS CLAVE

```
proyecto/
├── test_gait.ino                    ← Código Arduino (con protocolo integrado)
├── gui_qpod_config.py              ← Interfaz gráfica
├── quickstart_config.py            ← Carga rápida
├── default_config.json             ← Configuración por defecto
├── qpod_config_202604231200.json   ← Tus configs guardadas
├── README_CONFIGURACION.md         ← Manual completo
├── INTEGRACION_PASO_A_PASO.md      ← Guía integración Arduino
└── QUICK_REFERENCE.md              ← Este archivo
```

---

## 🔧 TROUBLESHOOTING

| Problema | Solución |
|---|---|
| "Puerto COM no aparece" | Drivers CH340/FTDI + reiniciar VS Code |
| "Arduino no responde" | Verifica serial_process() en loop() |
| "Error: módulo serial" | `pip install pyserial` |
| "Valores no persisten" | Usa botón "EEPROM_SAVE" en GUI |
| "GUI no se abre" | Necesitas display (SSH no funciona) |

---

## 💾 WORKFLOW TIPICO

```
1. Conectar Arduino
2. Abrir GUI: python gui_qpod_config.py
3. Tab "Calibración" → Ajustar servos
4. Tab "Posturas" → Aumentar ganancias
5. Tab "Gait" → Optimizar timings
6. Button "💾 Guardar JSON" → backup
7. Button "📤 → Arduino (EEPROM)" → guardar permanente
8. Desenchufar/enchufar Arduino
9. Verificar que se mantienen cambios ✓
```

---

## 🎯 PUNTOS CLAVE

✅ **Siempre respaldos:** Guarda JSON antes de experimentar  
✅ **Cambios incrementales:** Modifica 1 parámetro a la vez  
✅ **Prueba en vivo:** La GUI permite ver cambios sin recompilar  
✅ **EEPROM es segura:** 1024 bytes, usas ~150  
✅ **Baud rate:** SIEMPRE 115200  

---

## 🚀 INICIO RÁPIDO (5 MINUTOS)

1. Abre PowerShell
2. ```powershell
   cd f:\Documentos\Jota\jRobot\mini Q-Pod
   python gui_qpod_config.py
   ```
3. Selecciona puerto COM → Conectar
4. ¡A calibrar!

---

## 📞 COMANDOS PYTHON DESDE TERMINAL

```powershell
# Listar puertos
python -c "import serial.tools.list_ports; print([p[0] for p in serial.tools.list_ports.comports()])"

# Test rápido de conexión
python quickstart_config.py

# GUI completa
python gui_qpod_config.py
```

---

**¡Listo para empezar!** 🤖

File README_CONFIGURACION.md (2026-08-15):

# 📋 Q-POD MINI - SISTEMA DE CONFIGURACIÓN EN TIEMPO REAL

## 🎯 Descripción General

Este sistema permite:
✅ Parametrizar el robot **sin recompilar código**  
✅ Guardar/cargar configuraciones en **JSON**  
✅ Almacenar parámetros en **EEPROM del Arduino**  
✅ Ver estado en tiempo real (NRF24, PCA9685, ángulos)  
✅ Calibrar servos interactivamente  

---

## 🔧 COMPONENTES

### 1. **GUI Python** (`gui_qpod_config.py`)
Interfaz gráfica multiTab:
- **Tab 1 - Estado:** Monitoreo en vivo de hardware
- **Tab 2 - Calibración:** Edición de ángulos A/Center/B
- **Tab 3 - Posturas:** Ganancias standPose
- **Tab 4 - Gait:** Ganancias y timings de ciclo de marcha
- **Tab 5 - Avanzado:** Parámetros control remoto
- **Tab 6 - Log:** Terminal de debug

### 2. **Protocolo Serial** (`serial_protocol.cpp`)
Comunicación bidireccional Arduino ↔ Python
- Comandos para ajuste en vivo
- Lectura de estado
- Manejo de EEPROM

### 3. **Configuración** (archivos JSON)
Almacenamiento de parámetros portátil

---

## 🚀 INSTALACIÓN

### Paso 1: Instalar Python + dependencias
```bash
# Descargar Python 3.8+
# https://www.python.org/downloads/

# En PowerShell:
pip install pyserial
```

### Paso 2: Copiar archivos Python
```
Tu proyecto/
├── gui_qpod_config.py          ← Interfaz
├── configs/
│   ├── default_config.json      ← Configuración por defecto
│   └── mi_config.json           ← Tus propias configs
```

### Paso 3: Integrar protocolo en Arduino

**Abre `test_gait.ino` y sigue estos pasos:**

#### 3.1 - Añade INCLUDES al principio
```cpp
#include <EEPROM.h>
```

#### 3.2 - Después de definiciones globales, copia la sección EEPROM
Copia TODO el contenido de `serial_protocol.cpp` en tu sketch, justo después de las definiciones de variables globales.

#### 3.3 - En setup(), añade:
```cpp
void setup() {
  // ... código existente ...
  
  Serial.begin(115200);
  delay(600);
  
  // ← AÑADE ESTAS LÍNEAS
  eeprom_init();
  Serial.println("EEPROM inicializado");
  // ← FIN AÑADIDAS
  
  // ... resto del setup ...
}
```

#### 3.4 - En loop(), al final, añade:
```cpp
void loop() {
  // ... código existente de NRF24, control, gait, etc ...
  
  // ← AÑADE ESTA LÍNEA al final del loop()
  serial_process();
  // ← FIN AÑADIDA
}
```

---

## 📊 CÓMO USAR

### 1. Conectar y calibrar

```
1. Abre Python → gui_qpod_config.py
2. Selecciona tu puerto COM (ej: COM3)
3. Haz clic en "Conectar"
4. Ve a Tab "Calibración"
5. Selecciona un servo (ej: L1_COXA)
6. Mueve los sliders A / Center / B
7. Haz clic "Enviar" para aplicar en vivo
```

### 2. Guardar configuración

```
1. Una vez calibrado, haz clic "💾 Guardar JSON"
2. Selecciona nombre: ej "qpod_config_202604231200.json"
3. Se guarda automáticamente
```

### 3. Enviar a EEPROM del robot

```
1. Haz todos tus cambios
2. Haz clic "📤 → Arduino (EEPROM)"
3. Los parámetros se guardan en memoria del Arduino
4. El robot recordará la config **incluso sin alimentación**
```

### 4. Cargar configuración anterior

```
1. Haz clic "📂 Cargar JSON"
2. Selecciona archivo anterior
3. Los valores se actualizan en GUI
4. Haz clic "📤 → Arduino" para enviar al robot
```

---

## 🎛️ PARÁMETROS EXPLICADOS

### **Calibración**
- **Ángulo A:** Extremo 1 del servo (0-180°)
- **Ángulo Center:** Centro calibrado (típicamente 90°)
- **Ángulo B:** Extremo 2 del servo (0-180°)

### **Postura Base (StandPose)**
- **Ganancia Coxa:** Cuánto abren las patas lateralmente (0.0 = juntas, 1.0 = máximo)
  - **Recomendado: 0.45-0.55**
- **Ganancia Altura:** Cuánto se baja el robot (0.0 = normal, 1.0 = mínimo)
  - **Recomendado: 0.65-0.75**

### **Gait (Marcha)**
- **Ganancia Coxa:** Amplitud de pasos adelante/atrás (0.1-0.4)
- **Ganancia Lift:** Altura levantada de pata (0.2-0.5)
- **Timings:**
  - **LIFT (ms):** Tiempo levantamiento → **150-180**
  - **SWING (ms):** Tiempo movimiento horizontal → **180-220**
  - **DROP (ms):** Tiempo apoyo → **150-180**
  - **PUSH (ms):** Tiempo empuje → **180-220**

---

## 🔄 PROTOCOLO SERIAL

### Formato comandos:
```
[CMD] [ARG1] [ARG2] ...
```

### Ejemplos:

```
A 0 50              → Set angleA[servo0] = 50°
C 0 90              → Set angleCenter[servo0] = 90°
B 0 150             → Set angleB[servo0] = 150°

STAND_COXA 0.45     → StandPose coxa gain = 0.45
STAND_HEIGHT 0.70   → StandPose height gain = 0.70

GAIT_COXA 0.28      → Gait coxa gain = 0.28
GAIT_LIFT 0.30      → Gait lift gain = 0.30

GAIT_LIFT_MS 150    → Fase lift = 150ms
GAIT_SWING_MS 180   → Fase swing = 180ms

EEPROM_A 0 50       → Guardar en EEPROM: angleA[0] = 50
EEPROM_SAVE         → Confirmar y guardar TODO

STATE               → Obtener estado NRF/PCA/Batería
ANGLES              → Obtener ángulos actuales
INFO                → Listar comandos disponibles
```

---

## 📁 ESTRUCTURA EEPROM

El Arduino Nano tiene **1024 bytes** de EEPROM.  
Tu sistema usa ~142 bytes:

```
Offset  | Tamaño | Contenido
--------|--------|--------------------
0       | 1      | Magic (0xAA)
1-39    | 39     | angleA[13] (3 bytes c/u)
40-78   | 39     | angleCenter[13]
79-117  | 39     | angleB[13]
118-133 | 16     | Ganancias (4 float)
134-141 | 8      | Timings (4 uint16)
--------|--------|
Total   | ~142   | Uso
```

Sobran **~880 bytes** para futuros datos.

---

## 🐛 TROUBLESHOOTING

### Q: "Puerto COM no aparece"
**A:** 
1. Instala drivers CH340 o FTDI según tu Arduino
2. Reinicia VS Code
3. Desenchufa/enchúfa Arduino

### Q: "Error: módulo serial no encontrado"
**A:** Ejecuta en PowerShell:
```powershell
pip install pyserial
```

### Q: "Envío a Arduino sin respuesta"
**A:**
1. Abre Monitor Serial de Arduino IDE → verifica baud rate **115200**
2. Comprueba que `serial_process()` está en loop()
3. Envía comando "INFO" para verificar conectividad

### Q: "Valores no se guardan en EEPROM"
**A:**
1. Verifica que llamaste `eeprom_init()` en setup()
2. Usa botón "📤 → Arduino" al final
3. Verifica con Monitor Serial que dice "✓ GUARDADO EN MEMORIA"

---

## 📝 EJEMPLO DE FLUJO COMPLETO

```
1. Arduino subido con serial_protocol.cpp integrado ✓
2. Abre GUI Python → conecta a COM3
3. Calibra L1_COXA: A=50, C=90, B=150
4. Ajusta StandPose: Coxa=0.50, Height=0.72
5. Prueba movimiento con control PS2J
6. Si se ve bien: "💾 Guardar JSON" → config_20260423.json
7. "📤 → Arduino" → parámetros en EEPROM ✓
8. Desenchufa/enchúfa Arduino
9. Verifica que sigue con misma postura ✓
```

---

## 🔗 PRÓXIMOS PASOS

1. **Mejora de easing:** Implementar suavizado en interpolación
2. **Sensores:** Integrar lecturas de batería y estado PCA9685
3. **Graficación:** Mostrar trayectorias en tiempo real
4. **Exportación:** Guardar historiales de pruebas

---

## ⚠️ NOTAS IMPORTANTES

- **No toques EEPROM sin saber qué haces** → riesgo de perder datos
- **Siempre respaldos:** Guarda configs JSON antes de experimentar
- **Baud rate:** DEBE ser 115200 tanto en Arduino como Python
- **Delays mínimos:** El protocolo no bloquea, es seguro para tiempo real

---

## 📞 SOPORTE

Si tienes dudas:
1. Revisa el tab "Log" en GUI para debug
2. Abre Monitor Serial de Arduino IDE para ver mensajes raw
3. Comprueba que los comandos siguen el formato exacto

¡Éxito con tu Q-POD! 🚀

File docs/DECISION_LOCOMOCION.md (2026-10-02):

# Decisión de locomoción — Pico WH/RP2040

**Estado:** adoptada en firmware; carga, cableado y validación física
deliberadamente fuera de este cambio.

## Decisión

La **Raspberry Pi Pico WH con RP2040** queda seleccionada como plataforma de
locomoción. `mini_qpod_pico_walk_mvp/` implementa su envoltura usando el núcleo
compartido; el Nano ATmega328P conserva una envoltura de referencia. Ninguno se
carga ni se modifica físicamente como parte de esta decisión.

La identificación está confirmada por la serigrafía física comunicada por el
usuario y el FQBN `rp2040:rp2040:rpipicow`. La ESP32-S3 SuperMini se reserva para
sensores/IMU posteriores; la imagen del proveedor indica **ESP32-S3 FH4R2**, dato
pendiente de comprobar sobre la placa física.

## Evidencia de capacidad

| Medida compilada en esta base | Resultado | Lectura |
|---|---:|---|
| Nano, `mini_qpod_ik_walk_mvp` | 30.656/30.720 B flash (99%); 1.518/2.048 B RAM (74%) | Restan 64 B de flash y 530 B de RAM: no queda margen responsable para extender locomoción. |
| Pico WH, `mini_qpod_pico_walk_mvp` | 335.200/2.093.056 B flash (16%); 71.000/262.144 B RAM (27%) | Compilación de locomoción compartida; no es prueba física. |

El RP2040 dispone de dos Cortex-M0+ hasta 133 MHz y 264 kB de SRAM; el Nano
ATmega328P opera a 16 MHz con 2 kB de SRAM y 32 kB de flash (2 kB reservados
para bootloader). Véanse las especificaciones oficiales de
[RP2040](https://www.raspberrypi.com/documentation/microcontrollers/microcontroller-chips.html)
y [Arduino Nano](https://store.arduino.cc/products/arduino-nano).

La marcha actual llama a la actualización a 25 Hz (presupuesto de 40 ms) y, en
cada cuadro activo, calcula transformaciones e IK de las cuatro patas, usa
trigonometría y raíz cuadrada, construye la trayectoria y escribe los 12
canales del PCA9685. No hay medición de tiempo de peor caso sobre el Nano ni
sobre la Pico. La diferencia de frecuencia y memoria favorece a la Pico, pero
el RP2040 sigue siendo Cortex-M0+ y no debe asumirse una FPU de hardware:
cualquier implementación futura debe medir el tiempo de cuadro, I²C y radio
antes de validar movimiento.

## Adaptación que será necesaria después

No se realiza aquí ninguna migración física. La futura validación deberá conservar, sin reinterpretar,
la geometría y la calibración definidas en
[ik_constraints.md](ik_constraints.md) y
[ESPECIFICACION_TECNICA.md](../ESPECIFICACION_TECNICA.md).

| Interfaz | Estado actual Nano | Pico WH / etapa posterior |
|---|---|---|
| PCA9685 | I²C en A4/A5, dirección `0x40`, PWM a 50 Hz | Mover I²C a dos GPIO libres, conservar dirección/frecuencia/tabla; comprobar VCC y pull-ups para que SDA/SCL nunca superen 3,3 V o añadir adaptación de nivel. V+ de servos continúa separado. |
| NRF24L01 | RF24 con CE D9, CSN D10 y SPI AVR; canal 76, 250 kbps, dirección y paquete PS2J existentes | Asignar SPI, CE y CSN compatibles con la Pico; portar y comprobar la biblioteca RF24, modo de payload fijo y failsafe sin cambiar el contrato PS2J. El módulo es de lógica 3,3 V; verificar alimentación y cableado real. |
| Sensores/IMU | Pico usaba GP0/GP1 para MPU6050 y GP4/GP5 para UART Nano | ESP32-S3 SuperMini asumirá sensores después; GP8/GP9 se reservan para enlace Pico–S3, sin implementación actual. |

## Paridad C++ resuelta

Se instaló `ziglang` 0.16.0 y el arnés
`tools/ik_walk_simulator/test_parity.py` ahora detecta Zig cuando no hay
`g++`/`clang++`. Las **9** pruebas que realmente existen en `main` pasaron:
READY, trayectoria, fases, margen de soporte, paquete Control Lite, presets y
ciclos completos cuadro a cuadro. El conteo anterior de 10 era incorrecto.
Esta evidencia prueba equivalencia Python/C++ host, no temporización de MCU ni
comportamiento físico.

## Siguiente paso concreto

Antes de implementar la migración, cerrar la preparación de la etapa 3:
confirmar físicamente la revisión de la Pico W, el nivel lógico de la placa
PCA9685, el cableado NRF24 y el corte de energía. Después crear un diseño de
pines y un plan de pruebas de banco para Pico, sin energizar servos hasta que
ese diseño sea revisado.

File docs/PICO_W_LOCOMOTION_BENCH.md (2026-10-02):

# Pico WH locomotion — conexiones y banco

Este documento describe el firmware `mini_qpod_pico_walk_mvp/`. No autoriza
cargarlo, conectar V+ de servos ni mover el robot sin una revisión física
posterior.

## Mapa de conexiones propuesto

```text
Pico WH (3,3 V)                        PCA9685
--------------                         -------
GP0  (I2C0 SDA) ---------------------> SDA
GP1  (I2C0 SCL) ---------------------> SCL
3V3 ----------------------------------> VCC lógico (*)
GND ----------------------------------> GND lógico

Fuente externa de servos (+) ---------> V+          (*)
Fuente externa de servos (GND) -------> GND --------+---- Pico GND

Pico WH (3,3 V)                        NRF24L01
--------------                         -------
GP16 (SPI0 RX/MISO) <----------------- MISO
GP17 (GPIO CSN) ----------------------> CSN
GP18 (SPI0 SCK) ----------------------> SCK
GP19 (SPI0 TX/MOSI) ------------------> MOSI
GP20 (GPIO CE) -----------------------> CE
3V3 ----------------------------------> VCC
GND ----------------------------------> GND
IRQ -----------------------------------> sin conexión por ahora (*)

Pico WH (3,3 V)                        ESP32-S3 SuperMini (posterior)
----------------                        --------------------------------
GP8  (UART TX reservado) -------------> RX
GP9  (UART RX reservado) <------------- TX
GND -----------------------------------> GND
```

`(*)` requiere confirmación física antes de conectar: verificar la serigrafía
del PCA9685, su VCC lógico, sus resistencias pull-up y que ninguna señal I²C
sea elevada a 5 V. Si la placa obliga pull-ups a 5 V, usar adaptación bidireccional
de nivel o una placa configurada a 3,3 V. V+ solo alimenta servos y permanece
separado del 3V3 de la Pico; todas las masas deben ser comunes. Confirmar además
la alimentación estable de 3,3 V del NRF24 y la ruta física de cada SPI/CE/CSN.

La UART GP8/GP9 queda solo reservada: no se inicializa y no hay código S3. GP9
coincide con el pin Touch de la estación de sensores histórica; si ese arnés
sigue conectado debe retirarse antes de usar la UART. Este mapa corresponde al
controlador de locomoción Pico WH.

## Procedimiento de banco previo a validación física

1. Sin USB ni alimentación de servos, inspeccionar continuidad, GND común,
   polaridad de V+, VCC lógico PCA y 3,3 V del NRF24 con documentación de cada
   módulo. No aplicar 5 V a ningún GPIO de la Pico.
2. Con el robot sin alimentación de servos, compilar solamente:
   `arduino-cli compile --libraries libraries --fqbn rp2040:rp2040:rpipicow mini_qpod_pico_walk_mvp`.
   Esta etapa no realiza carga ni abre puertos.
3. Antes de una futura carga autorizada, revisar que el código llama a
   `pwmOff()` inmediatamente después de `pca.begin()` y tras configurar 50 Hz.
   Verificar además `X` y el failsafe de 500 ms por radio en revisión de código.
4. En una futura sesión física aprobada, mantener V+ de servos desconectado y
   medir primero las líneas I²C/SPI. Solo después de registrar voltajes y PWM
   apagado podrá definirse una prueba de READY separada. Nunca usar este
   documento como autorización para energizar o mover.

## Verificación host

```powershell
arduino-cli compile --libraries libraries --fqbn arduino:avr:nano:cpu=atmega328old mini_qpod_ik_walk_mvp
arduino-cli compile --libraries libraries --fqbn rp2040:rp2040:rpipicow mini_qpod_pico_walk_mvp
python -m unittest tools.ik_walk_simulator.test_parity -v
```

La paridad compara el núcleo C++ con el simulador Python. No comprueba señales,
tiempo de cuadro en RP2040, radio real, PCA real ni movimiento físico.

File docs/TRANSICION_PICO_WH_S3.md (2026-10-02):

# Transición Pico WH — ESP32-S3

La Pico WH queda dedicada a IK, marcha, PCA9685 y NRF24/Control Lite. La
ESP32-S3 SuperMini sustituirá sensores/IMU en una etapa posterior; el texto
«ESP32-S3 FH4R2» procede de imágenes del proveedor y debe verificarse en la
placa física antes de usarlo.

## Cableado actual de la Pico: revisión documental

| Acción | Cable o pin | Estado |
|---|---|---|
| Conservar | GND común de la lógica, PCA9685 y fuente de servos | Requisito de seguridad confirmado en documentación; confirmar continuidad física. |
| Conservar | USB de la Pico WH para futura programación/serial | Documentado; no se usa para alimentar servos. |
| Retirar de GP0/GP1 | SDA/SCL del MPU6050 histórico (`0x68`) | Confirmado en código histórico; comprobar que son esos dos cables en el robot antes de retirarlos. GP0/GP1 pasan a PCA9685. |
| Retirar de GP4 | UART Pico TX → Nano D2 | Documentado en firmware IMU; confirmar cable físico. Ya no pertenece a la arquitectura de locomoción. |
| No conectar | GP5 ← Nano D3 | Estaba reservado en código y declarado desconectado; verificar que siga sin cable. |
| Retirar si existe | Arnés Touch en GP9 de la estación de sensores | Documentado en `mini_qpod_pico_sensor_station`; pendiente confirmar si esa estación es la instalada. GP9 se reserva para S3 RX. |
| Conectar después de inspección | PCA9685: GP0/SDA, GP1/SCL, GND y VCC lógico 3,3 V | Mapa de firmware; confirmar VCC/pull-ups de la placa antes de conectar. V+ de servos sigue desconectado. |
| Conectar después de inspección | NRF24: GP16 MISO, GP17 CSN, GP18 SCK, GP19 MOSI, GP20 CE, 3V3 y GND | Mapa de firmware; confirmar pinout y alimentación 3,3 V del módulo. |
| Reservar, no conectar todavía | GP8 TX ↔ RX S3 y GP9 RX ↔ TX S3, con GND común | No hay firmware ni protocolo S3 en esta etapa. |

Los demás pines de la estación histórica (GP2/3, GP6/7, GP10, GP13–15 y
GP26/27) solo constan en su sketch. No deben suponerse conectados ni retirarse
sin inspección física.

El próximo objetivo físico es READY en Pico WH y, solo después de su cierre
registrado, Caminata lenta. Este documento no autoriza cargar firmware,
energizar V+ ni mover servos.

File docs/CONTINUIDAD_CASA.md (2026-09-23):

# Continuidad Mini Q-POD — oficina → casa

El repositorio es Git normal en GitHub y no depende de una sesión virtual:
`https://github.com/Jcabroc/mini-qpod.git`.

## Estado

- Rama: `feature/ik-servo-mapping`.
- Último commit publicado: `51da32f` (`fix: pace console after Nano startup`).
- `main` no se ha fusionado ni modificado.
- En el PC de oficina hay cambios locales pendientes en `tools/servo_mapping_console/console.py` y `ABRIR_CONSOLA_SERVOS.bat`; revisar y publicar antes de usarlos en casa.
- El Nano tiene cargado `nano_servo_mapping`; no se ha vuelto a cargar después de `51da32f`.

Clonar en casa:

```powershell
git clone https://github.com/Jcabroc/mini-qpod.git
cd mini-qpod
git switch --track origin/feature/ik-servo-mapping
git status
```

Para una copia ya clonada:

```powershell
git fetch --all --prune
git switch feature/ik-servo-mapping
git pull --ff-only
```

## Trabajo realizado

La IK Python está en `tools/ik_simulator/` y el Pose Lab en `tools/ik_pose_lab/`.
La geometría oficial es: chasis 93 × 93 mm, COXA 42.294 mm, FÉMUR 60.611 mm,
TIBIA 88.714 mm; origen en el centro geométrico, +X derecha, +Y frontal y +Z
arriba. El yaw es mecánico/radial, no eléctrico. Las restricciones y capturas CAD
están en `docs/ik_constraints.md` y `docs/reference/cad/`; las cotas CAD no son
límites eléctricos.

`nano_servo_mapping/` es firmware independiente de `mini_qpod_mvp/`. No usa
EEPROM y no incluye `SAVE`, `LOAD`, `DEFAULTS`, `EXPAND`, `STAND`, `LEG` ni
`WALK`. Arranca con los 13 canales apagados; `SELECT` no energiza y solo `ARM`
puede iniciar PWM. Mantiene IMU reciente (<250 ms), inclinación ±12°, watchdog
de host de 1 s, apagado `OFF`/`X`, activación exclusiva y rampa `MOVE` de 10°/s.
El primer `ARM` aplica inmediatamente el ángulo.

`tools/servo_mapping_console/` usa `pyserial`, LF, log con timestamps, espera el
banner y las 13 líneas CONFIG antes de `PING` cada 250 ms. Bloquea localmente
`ARM` a CH0/90° y `MOVE` a 89–91°. `X` se envía al cerrar, con Ctrl+C, ante error
serial o IMU no saludable.

Instalación y ejecución:

```powershell
python -m pip install -r tools/servo_mapping_console/requirements.txt
python -m tools.servo_mapping_console.console --port COM9 --baud 115200 --select 0
```

`ABRIR_CONSOLA_SERVOS.bat` abre la misma herramienta en una ventana visible; el
prompt esperado es `qpod>`. `X` y Enter son la emergencia. Los logs van fuera del
repositorio, en `hardware_backups/`.
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

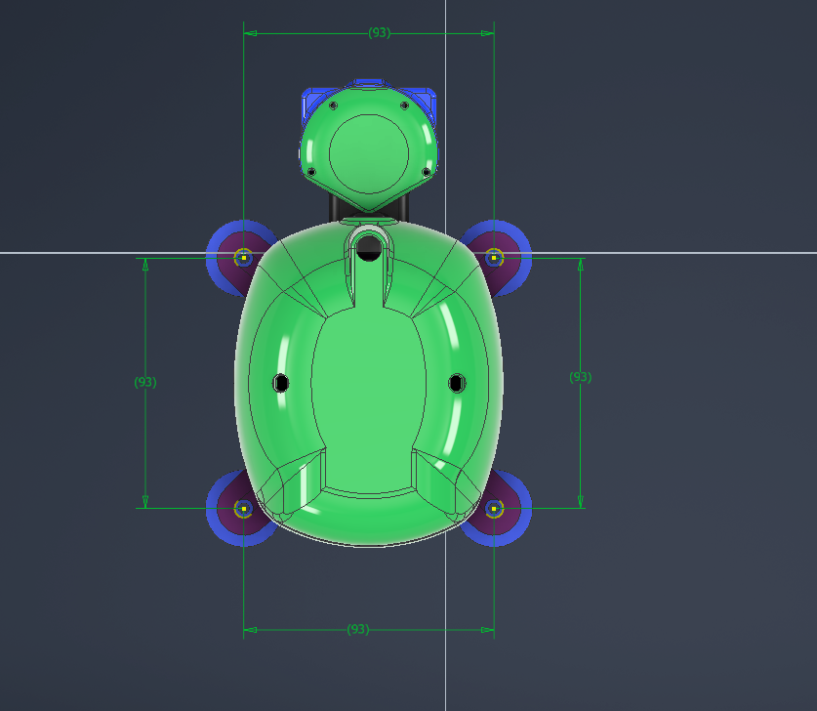
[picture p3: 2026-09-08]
docs/reference/cad/chassis_coxa_spacing.png

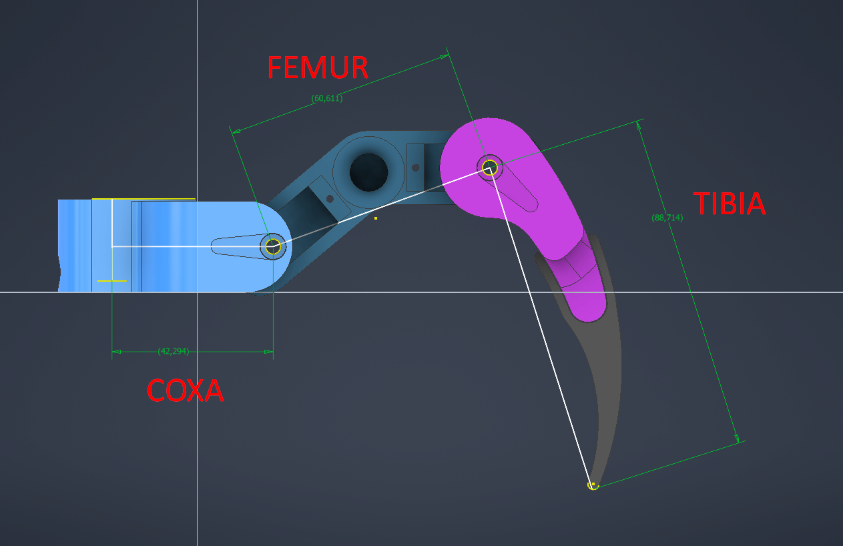
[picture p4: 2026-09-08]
docs/reference/cad/leg_link_lengths.png

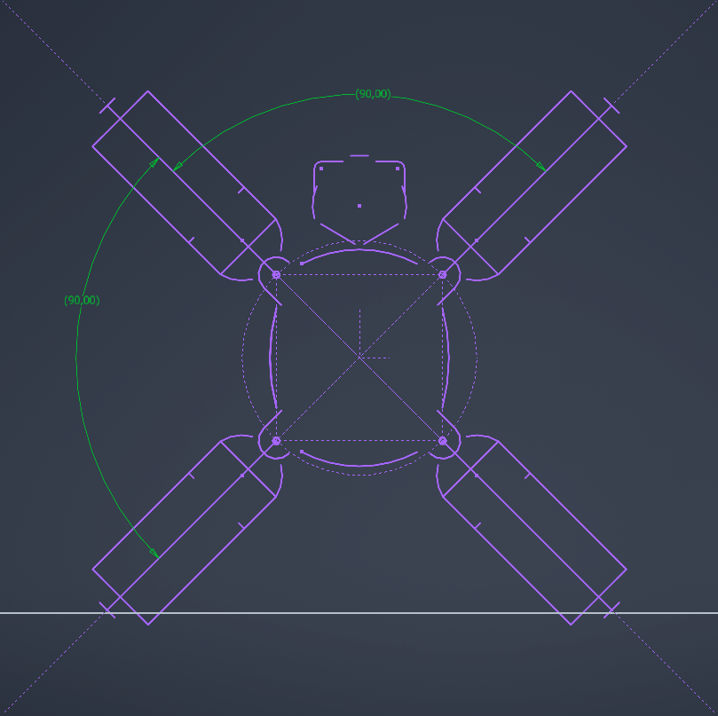
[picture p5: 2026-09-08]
docs/reference/cad/coxa_top_sweep_01.png

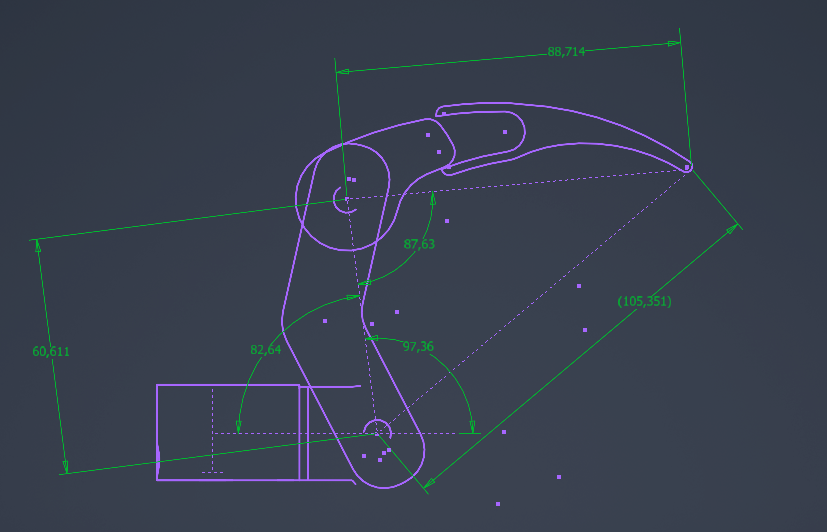
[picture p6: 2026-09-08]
docs/reference/cad/leg_lateral_workspace_04.png

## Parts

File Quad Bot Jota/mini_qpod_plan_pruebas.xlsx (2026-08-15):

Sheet: 00_Resumen
Mini Q-Pod · Plan maestro de pruebas e integración
Arquitectura definida
Bloque | Valor | Nota |  | Resumen rápido
Cerebro / sensores | Raspberry Pi Pico | Lee sensores y manda comandos al Nano |  | Servos activos mapeados | 13
Actuadores / movimiento | Arduino Nano | Controla PCA9685, servos, buzzer y NRF24 |  | Patas | 4
Bus de servos | 6 V dedicados | Buck 6 V 20 A solo para V+ de PCA9685 / servos |  | Canales PCA usados | CH0–CH12
Lógica general | 5 V | Buck 5 V para Nano y Pico; sensores Pico desde 3V3 de la Pico |  | Sensores Pico listados | 9
Comunicación Nano ↔ Pico | UART | Nano D3 → Pico GP5, Nano D2 ← Pico GP4, GND común
NRF24 | 3.3 V regulado dedicado | Nunca 5 V
Detalles críticos a verificar (los pequeños demonios que después tumban robots)
Ítem | Estado inicial | Por qué importa | Acción sugerida
Divisor o level shifter Nano TX → Pico RX | Pendiente confirmar | Nano trabaja a 5 V y la Pico no perdona en RX | Usar divisor resistivo o level shifter unidireccional
GND común en estrella | Debe existir | Sin masa común, la UART y los servos se vuelven poesía abstracta | Unir GND de bucks, Nano, Pico, PCA9685 y NRF
BMS / corte por bajo voltaje del pack 3S | Pendiente confirmar | Protege celdas 21700 y evita descarga profunda | Verificar BMS o alarma/cutoff de 3S
Fusible principal y switch general | Pendiente confirmar | Un corto sin fusible es un tutorial de humo | Agregar fusible automotriz/portafusible y switch maestro
Capacitor grande en línea de servos | Recomendado | Reduce caídas de tensión y picos al arrancar servos | 470–2200 µF cerca de PCA9685 V+ y GND
Capacitor cerca del NRF24 | Recomendado | El nRF24 suele caer por picos de corriente | 10–47 µF entre VCC y GND del módulo
Separación de alimentación USB / buck | Pendiente confirmar | Evita backfeeding cuando programes por USB | No mezclar 5 V USB con buck sin revisar caminos
Canales OFF al encender | Muy recomendado | Evita tirones al arranque | Mantener PCA9685 en OFF hasta comando explícito
Medición de corriente real en postura | Pendiente | Verifica margen del buck y cableado antes del gait | Medir consumo en reposo y con 1–2 patas en carga
Orden recomendado de trabajo
1. Nano + PCA9685 + un servo → validar señal y alimentación
2. Calibrar todos los servos y confirmar límites mecánicos
3. Postura base estable con el robot apoyado o suspendido
4. Pico sola: sensores uno por uno
5. UART Pico ↔ Nano con comandos PING / CENTER / STAND
6. Movimientos simples por pata
7. Secuencias cortas de apoyo
8. Primer gait lento, amplitud corta y consumo medido

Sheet: 01_Mapa_Pines
Mapa de pines y conexiones
Alimentación |  |  |  |  | UART Nano ↔ Pico
Elemento | Voltaje | Fuente | Notas |  | Función | Nano | Pico | Nivel | Nota
Servos MG90 | 6 V | Buck 6 V 20 A | Directo a PCA9685 V+ |  | TX Nano → RX Pico | D3 | GP5 | 5 V → 3.3 V | Usar divisor/level shifter recomendado
PCA9685 lógica | 5 V | Arduino Nano | Solo lógica I2C |  | RX Nano ← TX Pico | D2 | GP4 | 3.3 V → 5 V | Normalmente válido para Nano
Arduino Nano | 5 V | Buck 5 V | Entrando por pin 5V |  | GND común | GND | GND | — | Obligatorio
Raspberry Pi Pico | 5 V | Buck 5 V | Entrando por VSYS
NRF24L01 | 3.3 V | Regulador dedicado | Nunca 5 V
Sensores de la Pico | 3.3 V | Pin 3V3 de la Pico | Solo sensores ligeros
Sensores conectados a la Pico |  |  |  |  |  | Nano · estado / actuadores / radio
Sensor | Pin Pico | Voltaje | Tipo | Notas |  | Elemento | Pin Nano | Bus | Notas
MPU6050 SDA | GP0 | 3.3 V | IMU / I2C |  |  | Buzzer pasivo | D6 | GPIO/PWM
MPU6050 SCL | GP1 | 3.3 V | IMU / I2C |  |  | LED radio | D5 | GPIO
Sonar TRIG | GP2 | 3.3 V | HC-SR04 |  |  | PCA9685 SDA | A4 | I2C | Lógica 5 V desde Nano
Sonar ECHO | GP3 | Divisor | HC-SR04 | No entrar directo a 5 V |  | PCA9685 SCL | A5 | I2C | Lógica 5 V desde Nano
DHT | GP6 | 3.3 V | Temperatura / humedad |  |  | NRF24 CE | D9 | GPIO
Impacto | GP7 | 3.3 V | KY-031 |  |  | NRF24 CSN | D10 | SPI
Touch | GP9 | 3.3 V | TTP223 |  |  | NRF24 MOSI | D11 | SPI
Mini PIR | GP10 | 3.3 V | Movimiento |  |  | NRF24 MISO | D12 | SPI
LDR Izq | GP26 ADC0 | 3.3 V | Fotoresistor |  |  | NRF24 SCK | D13 | SPI
LDR Der | GP27 ADC1 | 3.3 V | Fotoresistor |  |  | NRF24 VCC | 3.3 V | Alimentación | Regulador dedicado
LED RGB (controlado por Pico)
Color | Pin | Resistencia | Controlador | Uso
Rojo | GP14 | 330 Ω | Pico | Estado / error
Verde | GP15 | 330 Ω | Pico | OK / listo
Azul | GP16 | 220 Ω | Pico | modo / actividad

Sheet: 02_Servos_PCA9685
Mapa de servos, rangos y calibración
Pata | Segmento | Canal | 70° | 90° | 110° | Longitud (mm) | Punto A | Centro | Punto B | Invertido | Offset | Mín seguro | Máx seguro | Probado | Notas
L1 | COAX | CH0 | ADELANTE | CENTRO | ATRÁS | 26.5 | 35 | 90 | 135 | No | 0 | 35 | 135 | Pendiente
L1 | FEMUR | CH1 | ABAJO | CENTRO | ARRIBA | 54 | 10 | 90 | 180 | No | 0 | 10 | 180 | Pendiente
L1 | TIBIA | CH2 | ARRIBA | CENTRO | ABAJO | 79.5 | 18 | 90 | 146 | No | 0 | 18 | 146 | Pendiente
R1 | COAX | CH3 | ATRÁS | CENTRO | ADELANTE | 26.5 | 40 | 90 | 130 | No | 0 | 40 | 130 | Pendiente
R1 | FEMUR | CH4 | ARRIBA | CENTRO | ABAJO | 54 | 170 | 90 | 10 | Sí | 0 | 10 | 170 | Pendiente
R1 | TIBIA | CH5 | ABAJO | CENTRO | ARRIBA | 79.5 | 30 | 90 | 160 | No | 0 | 30 | 160 | Pendiente
L2 | COAX | CH6 | ADELANTE | CENTRO | ATRÁS | 26.5 | 40 | 90 | 140 | No | 0 | 40 | 140 | Pendiente
L2 | FEMUR | CH7 | ARRIBA | CENTRO | ABAJO | 54 | 18 | 90 | 146 | No | 0 | 18 | 146 | Pendiente
L2 | TIBIA | CH8 | ABAJO | CENTRO | ARRIBA | 79.5 | 40 | 90 | 168 | No | 0 | 40 | 168 | Pendiente
R2 | COAX | CH9 | ATRÁS | CENTRO | ADELANTE | 26.5 | 40 | 90 | 134 | No | 0 | 40 | 134 | Pendiente
R2 | FEMUR | CH10 | ABAJO | CENTRO | ARRIBA | 54 | 18 | 90 | 180 | No | 0 | 18 | 180 | Pendiente
R2 | TIBIA | CH11 | ARRIBA | CENTRO | ABAJO | 79.5 | 18 | 90 | 140 | No | 0 | 18 | 140 | Pendiente
CUELLO | CUELLO | CH12 | DERECHA | CENTRO | IZQUIERDA | 87 desde centro | 45 | 90 | 135 | No | 0 | 45 | 135 | Pendiente

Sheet: 03_Checklist
Checklist maestro de pruebas
Métrica | Valor
Total tareas | -145
Completadas | 0
En prueba | 0
ID | Fase | Tarea | Responsable | Duración estimada | Dependencia | Estado | Fecha | Resultado / criterio de OK | Notas | Riesgo
A1 | Alimentación | Confirmar polaridad y voltajes de ambos bucks sin carga | HW | 15 min | — | Pendiente |  | Nano/Pico en voltaje correcto |  | Medio
A2 | 0.0% | Confirmar GND común entre bucks, Nano, Pico, PCA y NRF | HW | 10 min | A1 | Pendiente |  | Continuidad OK |  | Alto
A3 | Alimentación | Verificar divisor o level shifter Nano→Pico | HW | 20 min | A2 | Pendiente |  | RX Pico protegido |  | Alto
A4 | Alimentación | Confirmar BMS/corte bajo voltaje/fusible/switch maestro | HW | 20 min | A1 | Pendiente |  | Protección definida |  | Alto
N1 | Nano | Subir nano_00_test_serial | Nano | 10 min | A2 | Pendiente |  | Arranque estable por Serial |  | Bajo
N2 | Nano | Inicializar PCA9685 con todos los canales OFF | Nano | 15 min | N1 | Pendiente |  | Sin tirones al encender |  | Medio
N3 | Nano | Probar CH0 con 1 servo suspendido | Nano | 15 min | N2 | Pendiente |  | Movimiento suave y retorno |  | Medio
N4 | Nano | Probar todos los canales CH0–CH12 uno por uno | Nano | 60 min | N3 | Pendiente |  | Todos responden |  | Alto
N5 | Nano | Ajustar offsets, inversión y límites seguros | Nano | 90 min | N4 | Pendiente |  | Tabla de servos actualizada |  | Alto
N6 | Nano | Crear postura base / center / stand | Nano | 45 min | N5 | Pendiente |  | Robot quieto y simétrico |  | Alto
P1 | Pico | Subir pico_00_test_base | Pico | 10 min | A2 | Pendiente |  | Serial USB OK |  | Bajo
P2 | Pico | Probar IMU MPU6050 | Pico | 20 min | P1 | Pendiente |  | Lectura estable |  | Medio
P3 | Pico | Probar HC-SR04 (TRIG/ECHO con divisor) | Pico | 20 min | P1 | Pendiente |  | Distancia coherente |  | Medio
P4 | Pico | Probar DHT | Pico | 15 min | P1 | Pendiente |  | Lectura de temperatura/humedad |  | Bajo
P5 | Pico | Probar impacto, touch, PIR y LDR | Pico | 30 min | P1 | Pendiente |  | Todos los sensores cambian de estado |  | Medio
N7 | Nano | Probar NRF24 en Nano con regulador dedicado | Nano | 30 min | N1 | Pendiente |  | Ping/radio estable |  | Medio
I1 | Integración | PING Pico→Nano y respuesta OK | Integración | 15 min | N1,P1,A3 | Pendiente |  | UART estable |  | Alto
I2 | Integración | Comando CENTER desde Pico | Integración | 15 min | I1,N5 | Pendiente |  | Todos al centro por comando |  | Alto
I3 | Integración | Comando STAND desde Pico | Integración | 20 min | I2,N6 | Pendiente |  | Postura base por comando |  | Alto
I4 | Integración | Mover una pata individual por comando | Integración | 30 min | I3 | Pendiente |  | FL/R1/etc responden sin vibrar |  | Alto
I5 | Integración | Medir corriente en postura y microsecuencias | Integración | 30 min | I4 | Pendiente |  | Sin brownout / buck holgado |  | Alto
G1 | Gait | Secuencia corta de apoyo sin desplazamiento | Gait | 45 min | I5 | Pendiente |  | Estabilidad básica |  | Alto
G2 | Gait | Primer paso lento con amplitud corta | Gait | 45 min | G1 | Pendiente |  | Sin choque ni caída |  | Alto
G3 | Gait | Afinar velocidad, altura y consumo | Gait | 60 min | G2 | Pendiente |  | Camina repetible |  | Medio

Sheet: 04_Gantt
Cronograma tipo Gantt (editable)
Edita Inicio (día) y Duración. Las barras se recalculan al abrir en Excel.
 |  |  |  |  |  |  | 1 | 2 | 3 | 4 | 5 | 6 | 7 | 8 | 9 | 10 | 11 | 12 | 13 | 14 | 15 | 16 | 17 | 18 | 19 | 20
Fase | ID | Tarea | Responsable | Inicio | Duración | Fin | D1 | D2 | D3 | D4 | D5 | D6 | D7 | D8 | D9 | D10 | D11 | D12 | D13 | D14 | D15 | D16 | D17 | D18 | D19 | D20
Alimentación | A1 | Voltajes bucks | HW | 1 | 1 | 1 | 1
Alimentación | A2 | GND común | HW | 1 | 1 | 1 | 1
Alimentación | A3 | Divisor Nano→Pico | HW | 1 | 1 | 1 | 1
Nano | N1 | Serial base | Nano | 2 | 1 | 2 |  | 1
Nano | N2 | PCA OFF | Nano | 2 | 1 | 2 |  | 1
Nano | N3 | 1 servo CH0 | Nano | 3 | 1 | 3 |  |  | 1
Nano | N4 | Todos los servos | Nano | 4 | 2 | 5 |  |  |  | 1 | 1
Nano | N5 | Offsets / límites | Nano | 6 | 2 | 7 |  |  |  |  |  | 1 | 1
Nano | N6 | Postura base | Nano | 8 | 1 | 8 |  |  |  |  |  |  |  | 1
Pico | P1 | Base serial | Pico | 9 | 1 | 9 |  |  |  |  |  |  |  |  | 1
Pico | P2 | IMU | Pico | 9 | 1 | 9 |  |  |  |  |  |  |  |  | 1
Pico | P3 | Sonar | Pico | 10 | 1 | 10 |  |  |  |  |  |  |  |  |  | 1
Pico | P4 | DHT | Pico | 10 | 1 | 10 |  |  |  |  |  |  |  |  |  | 1
Pico | P5 | Resto sensores | Pico | 11 | 1 | 11 |  |  |  |  |  |  |  |  |  |  | 1
Nano | N7 | NRF24 | Nano | 11 | 1 | 11 |  |  |  |  |  |  |  |  |  |  | 1
Integración | I1 | PING UART | Integración | 12 | 1 | 12 |  |  |  |  |  |  |  |  |  |  |  | 1
Integración | I2 | CENTER | Integración | 13 | 1 | 13 |  |  |  |  |  |  |  |  |  |  |  |  | 1
Integración | I3 | STAND | Integración | 13 | 1 | 13 |  |  |  |  |  |  |  |  |  |  |  |  | 1
Integración | I4 | Mover una pata | Integración | 14 | 2 | 15 |  |  |  |  |  |  |  |  |  |  |  |  |  | 1 | 1
Integración | I5 | Medir corriente | Integración | 16 | 1 | 16 |  |  |  |  |  |  |  |  |  |  |  |  |  |  |  | 1
Gait | G1 | Secuencia apoyo | Gait | 17 | 1 | 17 |  |  |  |  |  |  |  |  |  |  |  |  |  |  |  |  | 1
Gait | G2 | Primer paso lento | Gait | 18 | 1 | 18 |  |  |  |  |  |  |  |  |  |  |  |  |  |  |  |  |  | 1
Gait | G3 | Afinado inicial | Gait | 19 | 2 | 20 |  |  |  |  |  |  |  |  |  |  |  |  |  |  |  |  |  |  | 1 | 1

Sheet: 05_Riesgos
Riesgos, síntomas y antídotos
Riesgo | Síntoma | Causa probable | Mitigación | Prioridad | ¿Verificado?
Brownout del Nano/Pico al mover servos | Reinicio o Serial cortado | Caída de tensión o masa mal distribuida | Capacitor, buck con margen, masas en estrella, medir consumo | Alta | Pendiente
NRF24 inestable | No enlaza o pierde paquetes | Picos de corriente / mala alimentación | Regulador dedicado + capacitor 10–47 µF | Media | Pendiente
Servo invertido o fuera de rango | Golpe mecánico o vibración | Offsets/límites mal cargados | Suspender robot y validar canal por canal | Alta | Pendiente
Lectura falsa del HC-SR04 | Distancias absurdas | ECHO sin divisor o ruido eléctrico | Divisor correcto y masa común | Media | Pendiente
Daño en RX de Pico | Comunicación muerta | 5 V directo desde Nano TX | Divisor/level shifter obligatorio | Alta | Pendiente
Backfeeding por USB | Comportamiento raro al programar | 5 V USB y buck empujando a la vez | Revisar rutas de 5 V y secuencia de conexión | Media | Pendiente

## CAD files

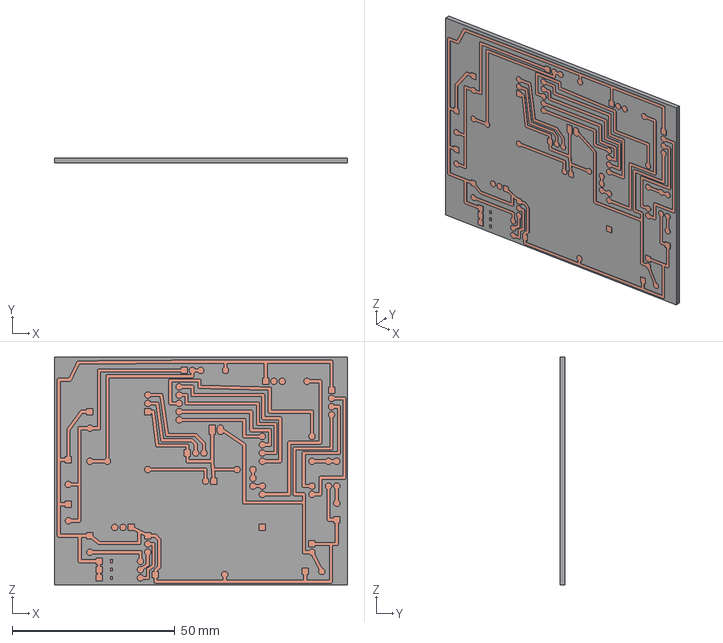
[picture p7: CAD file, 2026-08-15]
Quad Bot Jota/Modelos 3D Jota QuadBot/PCBs/Shield PCB miniQpod.stp
90.0 x 1.60 x 70.0 mm

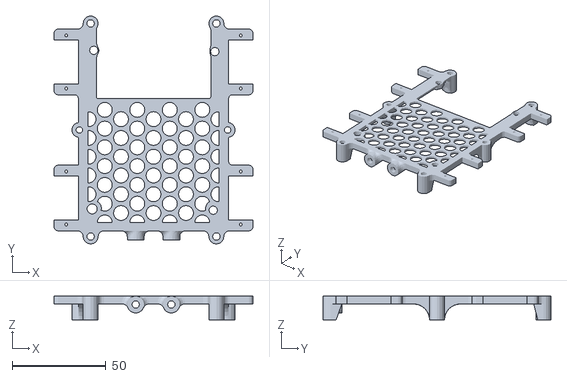
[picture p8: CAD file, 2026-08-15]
Quad Bot Jota/Modelos 3D Jota QuadBot/placa media PCB 2.5.stl
106.0 x 121.5 x 12.7

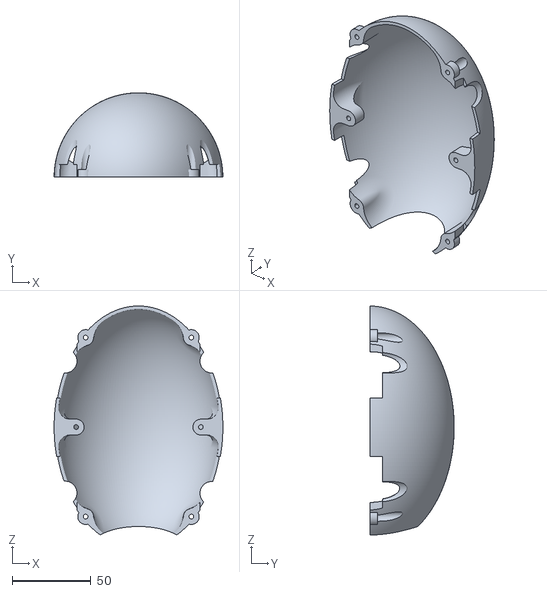
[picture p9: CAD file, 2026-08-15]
Quad Bot Jota/Modelos 3D Jota QuadBot/caparazon.stl
107.0 x 53.5 x 145.2

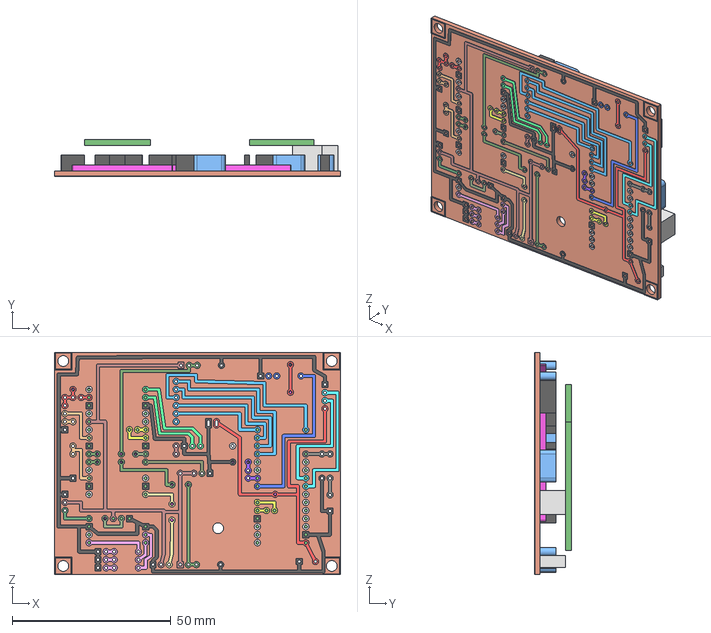
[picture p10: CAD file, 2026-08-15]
Quad Bot Jota/Modelos 3D Jota QuadBot/PCBs/final Shield PCB miniQpod.stp
90.0 x 11.8 x 70.0 mm

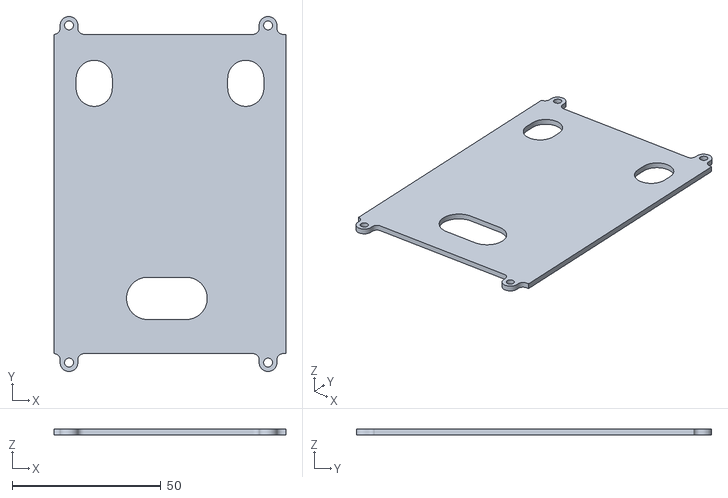
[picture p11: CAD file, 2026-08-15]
Quad Bot Jota/Modelos 3D Jota QuadBot/body_u_L_PCA_Neck.stl
78.0 x 119.5 x 2.00

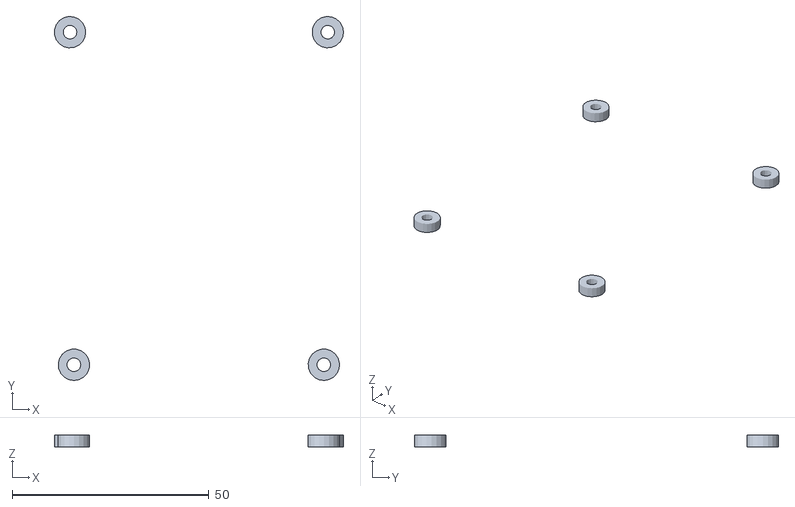
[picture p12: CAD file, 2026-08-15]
Quad Bot Jota/Modelos 3D Jota QuadBot/espaciadores pcb.stl
73.4 x 92.5 x 3.00

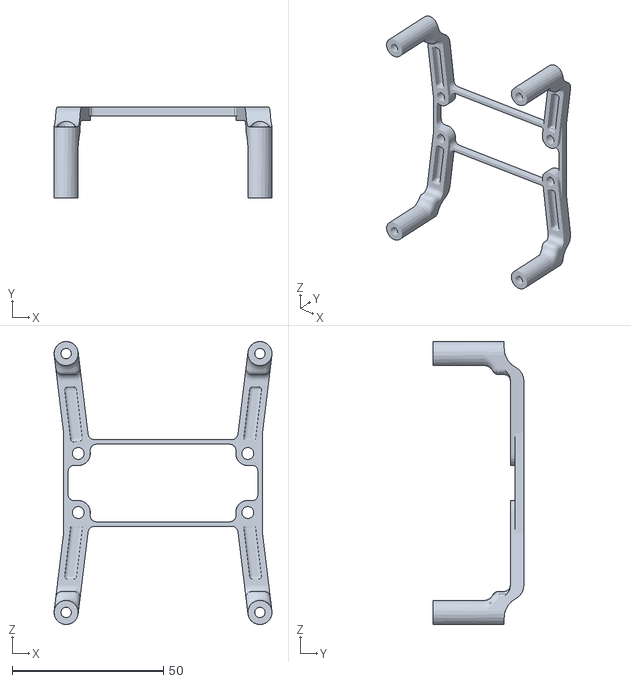
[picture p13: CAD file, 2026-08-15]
Quad Bot Jota/Modelos 3D Jota QuadBot/soporte PCA9685.stl
72.0 x 30.0 x 93.5

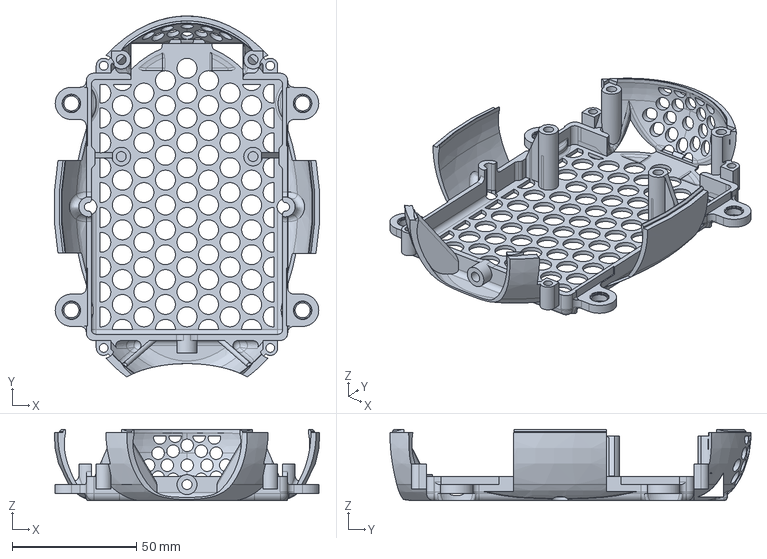
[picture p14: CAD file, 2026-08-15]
Quad Bot Jota/Modelos 3D Jota QuadBot/WATA 3.5.stp
106.7 x 145.2 x 28.7 mm

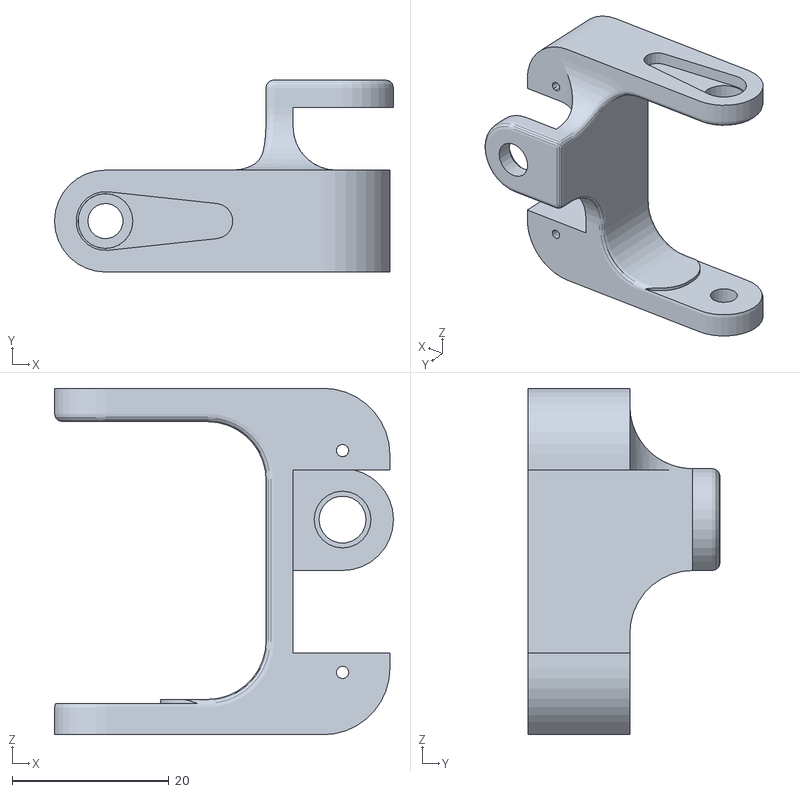
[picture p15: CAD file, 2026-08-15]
Quad Bot Jota/Modelos 3D Jota QuadBot/coax 2.0.stl
43.3 x 24.5 x 44.2

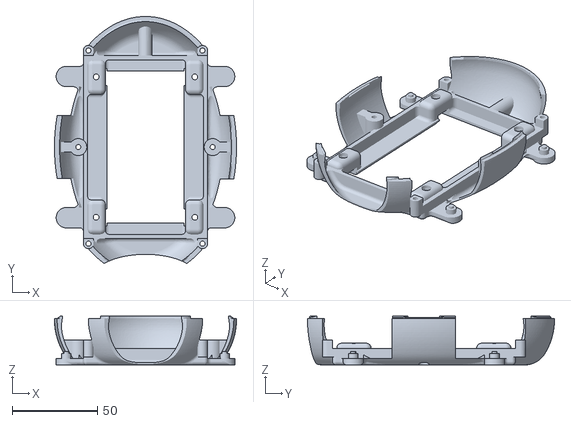
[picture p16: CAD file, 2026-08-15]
Quad Bot Jota/Modelos 3D Jota QuadBot/WATA.stl
107.0 x 145.2 x 28.7

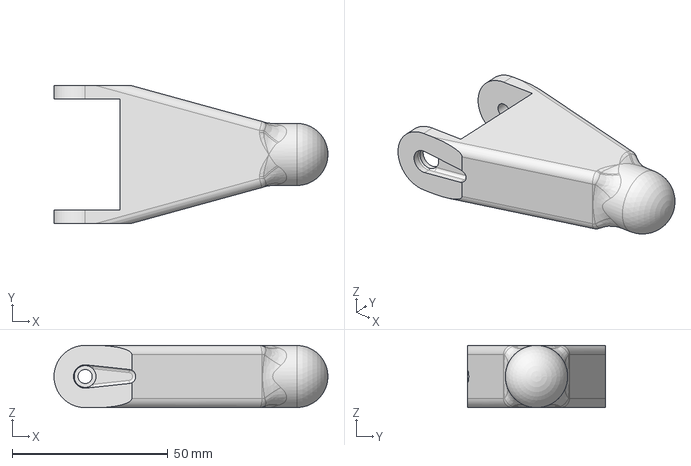
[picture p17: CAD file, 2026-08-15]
Quad Bot Jota/Modelos 3D Jota QuadBot/tibia 1.0.stp
88.0 x 44.2 x 20.0 mm

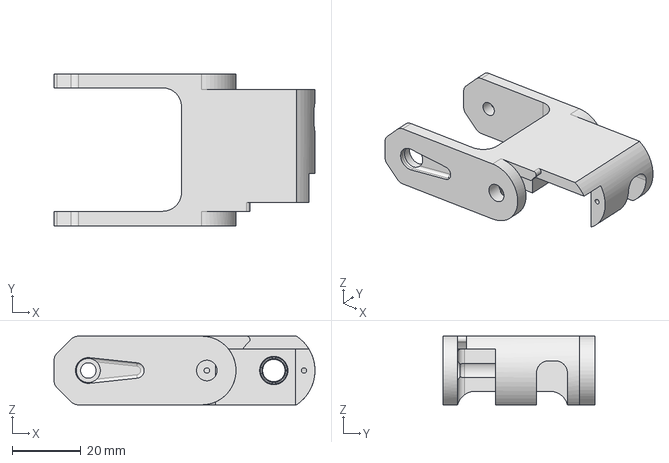
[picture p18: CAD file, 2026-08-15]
Quad Bot Jota/Modelos 3D Jota QuadBot/femur 1.1.stp
76.0 x 44.2 x 20.0 mm

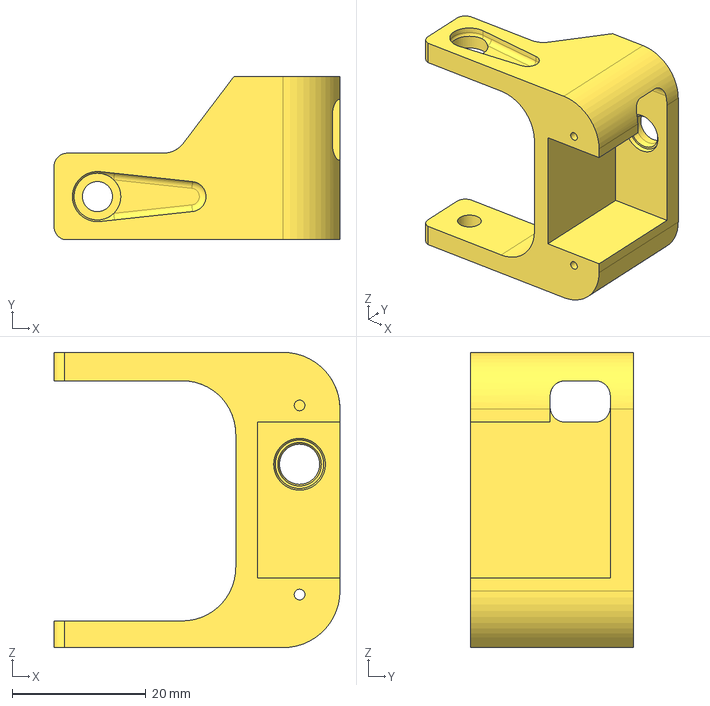
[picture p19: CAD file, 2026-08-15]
Quad Bot Jota/Modelos 3D Jota QuadBot/COAX 3.5.stp
42.8 x 24.5 x 44.2 mm

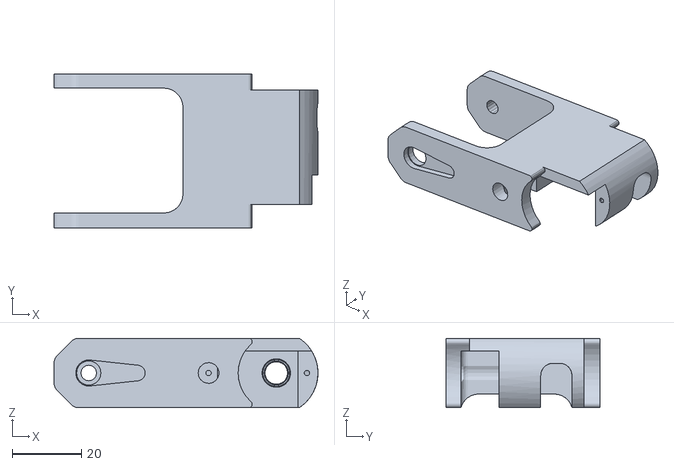
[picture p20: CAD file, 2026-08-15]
Quad Bot Jota/Modelos 3D Jota QuadBot/femur 1.0.stl
76.0 x 44.2 x 20.0

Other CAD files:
Quad Bot Jota/Modelos 3D Jota QuadBot/placa central.stp
Quad Bot Jota/Modelos 3D Jota QuadBot/placa media PCB.stl
Quad Bot Jota/Modelos 3D Jota QuadBot/wata 3.6.a.stp
Quad Bot Jota/Modelos 3D Jota QuadBot/placa media PCB 2.0.stl
Quad Bot Jota/Modelos 3D Jota QuadBot/Assembly1.iam
Quad Bot Jota/Modelos 3D Jota QuadBot/Assembly2.iam
Quad Bot Jota/Modelos 3D Jota QuadBot/COAX 3.5.stl
Quad Bot Jota/Modelos 3D Jota QuadBot/Cuerpo nuevo Jota.ipt
Quad Bot Jota/Modelos 3D Jota QuadBot/OldVersions/Assembly1.0001.iam
Quad Bot Jota/Modelos 3D Jota QuadBot/OldVersions/Assembly2.0004.iam
Quad Bot Jota/Modelos 3D Jota QuadBot/OldVersions/body_d_L_Screws.0034.ipt
Quad Bot Jota/Modelos 3D Jota QuadBot/OldVersions/body_u_L_PCA_Neck.0003.ipt
Quad Bot Jota/Modelos 3D Jota QuadBot/OldVersions/caparazon.0001.ipt
Quad Bot Jota/Modelos 3D Jota QuadBot/OldVersions/panza mini qpod 3.0.0009.ipt
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

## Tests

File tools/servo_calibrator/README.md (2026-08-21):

# Calibrador provisional Mini Q-POD

Aplicación local para Windows, hecha con Python, Tkinter y PySerial. Es una
herramienta de calibración puntual: no es POD Station, no abre un navegador, no
usa servidor, base de datos, Docker, React ni Electron.

## Instalar y ejecutar en Windows

Abra PowerShell en esta carpeta y ejecute:

```powershell
py -m pip install -r requirements.txt
py servo_calibrator.py
```

Tkinter suele venir incluido con Python para Windows. Si `py` no existe, instale
Python 3 desde python.org y marque **Add Python to PATH**.

Para revisar la interfaz sin hardware, elija `SIMULATED (sin hardware)` y pulse
**Conectar a 115200**. El simulador vive en memoria: nunca abre un puerto COM ni
controla servos.

## Flujo seguro de la interfaz

1. Conecte a 115200. La aplicación envía únicamente `OFF`, `STATUS`, `IMU` y
   `CONFIG`; no habilita ni mueve servos.
2. Confirme `IMU: OK` y el modo `SAFE_OFF`.
3. Pulse `CALIB (PWM OFF)`.
4. Elija una articulación y pulse `SELECT`. Esto no genera PWM.
5. Revise el primer ángulo. Pulse `ENABLE` solo con el robot elevado, potencia
   de servos bajo control físico y el horn libre de choque. El primer PWM puede
   producir movimiento inmediato.
6. Use `CENTER`, los pasos de ±1°/±5° o un ángulo manual. Solo el canal activo
   puede moverse.
7. Pulse el botón rojo `SERVOS OFF` ante cualquier comportamiento inesperado.
8. Para editar `LIMITS`, el calibrador manda primero `OFF`; pruebe de nuevo los
   límites antes de `SAVE`. `SAVE` y `LOAD` requieren `SAFE_OFF`.

La terminal acepta exclusivamente `OFF`, consultas, los comandos de calibración,
`SAVE`, `LOAD` y `HELP`. Bloquea `STAND`, `LEG`, `UNLOCK_WALK`, `WALK`,
`DEFAULTS` y cualquier comando desconocido.

Mientras está conectada, la aplicación envía `PING` cada 250 ms. Con un canal
activo en calibración, el Nano corta PWM y emite `[ABORT] HOST_TIMEOUT` si no
recibe actividad válida durante 1000 ms. Al cerrar normalmente, la aplicación
intenta enviar `OFF` antes de cerrar el puerto. Si falla una lectura o escritura,
bloquea los controles e indica que el estado físico no puede confirmarse.

## Semántica vigente del MVP

- El centro eléctrico es la referencia física de **90°** usada al montar el horn.
- `centerAngle` del firmware es la posición neutral/inicial configurable.
- `minAngle` y `maxAngle` son límites mecánicos; el firmware informa y aplica
  límites seguros efectivos con el margen global.
- `direction` es metadato existente para semántica articular futura; no invierte
  el ángulo eléctrico manual.

No se amplió la estructura EEPROM en esta etapa.

## Pruebas sin hardware

```powershell
py -m unittest discover -s tests -v
```

Las pruebas utilizan el puerto serial simulado y verifican la lista blanca local,
el apagado, selección sin PWM, activación individual, límites, aborto IMU y el
contrato estático del firmware. No abren puertos COM reales.

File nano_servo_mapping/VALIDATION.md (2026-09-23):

# Validación sin hardware — 2026-09-23

Rama `feature/ik-servo-mapping`, creada desde el estado limpio
`3d00207814a0123cb807f4cdc6271446b9082b00` de `feature/primitive-vision`.
La rama `feature/ik-simulator` apuntaba al mismo commit. No se alteró `main`.

Se revisó el pinout del MVP y el emisor Pico antes de implementar. La nueva
carpeta es independiente; no se modifica MVP, IK, Pose Lab ni configuración
existente. No se abrieron puertos seriales ni se cargó firmware. Sin commit/push.

## Resultados

- Arduino AVR 1.8.6, Adafruit PWM Servo Driver 3.0.2,
  `arduino:avr:nano:cpu=atmega328old`: compilación correcta.
- Flash: **16 276 / 30 720 bytes (52%)**.
- Variables globales SRAM: **942 / 2048 bytes (45%)**; quedan 1106 bytes
  para pila y variables locales. Es el informe estático del compilador, no una
  medición de profundidad máxima de pila ni prueba de ejecución sostenida.
- Núcleo C++ real compilado en PC con Zig 0.16.0: parser estricto, trama/checksum,
  frescura IMU, límites de los 13 canales, activación exclusiva, rechazo atómico,
  rampa, selección sin PWM, OFF/X, pérdida IMU, inclinación, watchdog,
  heartbeat, desbordamiento de millis y bloqueo por fallo de bus.
- IK: 12 pruebas correctas; Pose Lab: 5; calibrador existente: 28.
- Monitor de visión: script de simulación de parser correcto (no es una suite
  unittest; el descubrimiento informa cero casos aunque ejecuta sus asserts).
- `git diff --check`: correcto, incluyendo los archivos nuevos por intención
  de añadir al índice. No hay archivos ajenos incluidos.

## Pendiente antes de aceptar seguridad física

Verificar con alimentación de servos desconectada la identidad del firmware
después de una futura carga autorizada, señales FULL_OFF de los trece canales,
pinout real, cadencia IMU y tiempos de corte medidos. Comprobar que el host usado
mantiene PING y no envía comandos del calibrador anterior.

Los tests usan un PCA simulado; no certifican el estado eléctrico. Ante fallo de
I²C, STATUS indica `UNKNOWN_BUS_ERROR`; se solicita apagado y se bloquea nuevo
armado hasta reinicio. Sin cable OE independiente no se garantiza apagado ante
avería de bus o bloqueo del MCU. El corte de fuente sigue siendo necesario.

El primer ARM no tiene posición inicial conocida y puede producir un salto.
Los límites heredados con margen no prueban ausencia de colisiones. El
procedimiento detallado de CH0 y las referencias a medir están en README.md.
No se implementa una transformación mecánica desde datos todavía no medidos.

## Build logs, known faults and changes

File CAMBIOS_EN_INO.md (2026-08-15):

# 📋 CAMBIOS EN test_gait_INTEGRADO.ino

## 🎯 Resumen

Este archivo es el `test_gait.ino` **COMPLETAMENTE INTEGRADO** con:
✅ Protocolo Serial (comandos desde Python)  
✅ EEPROM Manager (guardado persistente)  
✅ Parámetros ajustables en tiempo real  

**Listo para usar con la GUI de Python sin modificaciones adicionales.**

---

## 🔄 CAMBIOS ESPECÍFICOS (5 pasos de integración)

### ✅ PASO 1: Include EEPROM
**Línea 7**
```cpp
#include <EEPROM.h>    // ← NUEVO
```

---

### ✅ PASO 2: Struct + Funciones EEPROM
**Después de `SERVO_MAX` (línea 58)**

Añadidas:
- `struct EEPROMData` - Estructura de datos EEPROM
- `eeprom_init()` - Inicializar EEPROM
- `eeprom_write()` - Guardar a EEPROM

Esto permite guardar:
```
- 13 ángulos × 3 (A, Center, B)
- 4 ganancias (float)
- 4 timings (uint16)
Total: ~140 bytes de 1024
```

---

### ✅ PASO 3: Variables Dinámicas
**Líneas 175-181**

Cambio importante - Variables ahora son `float` en lugar de `const`:
```cpp
// ANTES:
const uint16_t GAIT_LIFT_MS  = 180;
const float GAIT_COXA_GAIN = 0.28f;

// AHORA:
uint16_t GAIT_LIFT_MS  = 150;        // Variable
float GAIT_COXA_GAIN = 0.28f;        // Variable
```

También:
```cpp
// ANTES:
const float SAFE_HEIGHT_GAIN = 0.55f;
const float SAFE_COXA_GAIN   = 0.45f;

// AHORA:
float SAFE_HEIGHT_GAIN = 0.70f;      // Configurable
float SAFE_COXA_GAIN   = 0.45f;      // Configurable
```

---

### ✅ PASO 4: buildStandPose() mejorada
**Línea 354-368**

Ahora usa ganancias **dinámicas**:
```cpp
// ANTES:
standPose[0] = safeBlendFromCenter(angleCenter[0], coxaForward[0], 0.30f);

// AHORA:
standPose[0] = safeBlendFromCenter(angleCenter[0], coxaForward[0], SAFE_COXA_GAIN);
```

**Ventaja:** Cambias la ganancia desde la GUI y recalcula postura en vivo.

---

### ✅ PASO 5: Función serial_process()
**Línea 657-852**

Nueva función que **procesa comandos desde Python**:

#### 5a - Comandos en VIVO (sin guardar)
```cpp
// Cambia ángulos inmediatamente
A <ch> <angle>
C <ch> <angle>
B <ch> <angle>

// Cambia ganancias inmediatamente
STAND_COXA <valor>
STAND_HEIGHT <valor>
GAIT_COXA <valor>
GAIT_LIFT <valor>

// Cambia timings inmediatamente
GAIT_LIFT_MS <ms>
GAIT_SWING_MS <ms>
GAIT_DROP_MS <ms>
GAIT_PUSH_MS <ms>
```

#### 5b - Comandos EEPROM (guardado permanente)
```cpp
EEPROM_A <ch> <angle>
EEPROM_C <ch> <angle>
EEPROM_B <ch> <angle>
EEPROM_STAND_COXA <valor>
EEPROM_STAND_HEIGHT <valor>
EEPROM_GAIT_COXA <valor>
EEPROM_GAIT_LIFT <valor>
EEPROM_LIFT_MS <ms>
EEPROM_SWING_MS <ms>
EEPROM_DROP_MS <ms>
EEPROM_PUSH_MS <ms>
EEPROM_SAVE  ← Ejecuta guardado
```

#### 5c - Consultas
```cpp
STATE        → NRF/PCA/Modo
ANGLES       → Ángulos actuales
INFO         → Ayuda
```

---

### ✅ PASO 6: setup() modificado
**Línea 854-903**

Añadida línea después de `buildStandPose()`:
```cpp
// NUEVO
eeprom_init();
```

Esto carga los parámetros guardados al iniciar.

---

### ✅ PASO 7: loop() modificado
**Línea 954 (final)**

Última línea del loop:
```cpp
// NUEVO
serial_process();
```

Procesa comandos serial sin bloquear.

---

## 🎯 CÓMO USA LA GUI

### Flujo típico:

1. **GUI Python** → Envía comando `A 0 50`
   ```
   "Set ángulo A del servo 0 a 50°"
   ```

2. **Arduino recibe** → `serial_process()` lo ejecuta
   ```cpp
   angleA[0] = 50;
   targetAngle[0] = 50;    // Aplica inmediatamente
   ```

3. **Servo se mueve** en vivo

4. **Usuario hace clic** "📤 → Arduino (EEPROM)"
   ```
   GUI envía: EEPROM_A 0 50
   GUI envía: EEPROM_SAVE
   ```

5. **Arduino guarda** en EEPROM permanentemente

6. **Desenchufa/enchúfa** Arduino → ¡Se recuerda! ✓

---

## 📊 PARÁMETROS AHORA AJUSTABLES

### Desde GUI (sin recompilar):

| Parámetro | Tipo | Rango | Default |
|---|---|---|---|
| angleA[13] | int | 0-180 | * |
| angleCenter[13] | int | 0-180 | * |
| angleB[13] | int | 0-180 | * |
| SAFE_COXA_GAIN | float | 0.0-1.0 | 0.45 |
| SAFE_HEIGHT_GAIN | float | 0.0-1.0 | 0.70 |
| GAIT_COXA_GAIN | float | 0.0-1.0 | 0.28 |
| GAIT_LIFT_GAIN | float | 0.0-1.0 | 0.30 |
| GAIT_LIFT_MS | uint16 | 50-500 | 150 |
| GAIT_SWING_MS | uint16 | 50-500 | 180 |
| GAIT_DROP_MS | uint16 | 50-500 | 150 |
| GAIT_PUSH_MS | uint16 | 50-500 | 200 |

*= Valores por defecto en default_config.json

---

## ⚠️ CAMBIOS IMPORTANTES

1. **Valores nuevos más agresivos:**
   - `GAIT_LIFT_MS`: 180 → **150** (más rápido)
   - `GAIT_SWING_MS`: 220 → **180** (pasos más rápidos)
   - `GAIT_DROP_MS`: 180 → **150** (más estable)
   - `GAIT_PUSH_MS`: 220 → **200** (más natural)
   - `SAFE_HEIGHT_GAIN`: 0.55 → **0.70** (postura más baja)

2. **Variables dinámicas:**
   - Todos los timings ahora son `uint16_t` (no `const`)
   - Todas las ganancias ahora son `float` (no `const`)
   - Se pueden cambiar sin recompilar

3. **buildStandPose() mejorada:**
   - Usa ganancias dinámicas
   - Se puede recalcular con comando desde GUI

---

## 🚀 CÓMO USAR

### Compilar:
```
Arduino IDE → Selecciona Arduino Nano
Sube el código como siempre
```

### Controlar desde Python:
```bash
python gui_qpod_config.py
```

### Probar en terminal:
```bash
python quickstart_config.py
```

---

## 🔍 VERIFICACIÓN RÁPIDA

Para verificar que todo está integrado:

1. **Abre Monitor Serial** (Arduino IDE)
   - Baud: 115200
   - Envía: `INFO`
   - Debe responder con lista de comandos

2. **Desde PowerShell:**
   ```bash
   python quickstart_config.py
   ```
   - Carga configuración automáticamente
   - Debe ver "✓ ÉXITO"

3. **Desenchufa/enchúfa Arduino**
   - Debe recordar los parámetros
   - Postura debe ser igual

---

## 📁 COMPATIBILIDAD

✅ Compatible con GUI: `gui_qpod_config.py`  
✅ Compatible con quickstart: `quickstart_config.py`  
✅ Compatible con JSON: `default_config.json`  
✅ Protocolo serial: Bidireccional  
✅ EEPROM: ~140 bytes usados  

---

## 🎉 ¡LISTO!

Este archivo `.ino` está **completamente listo**:
- Copia/pega a Arduino IDE
- Compila sin cambios
- Sube a Nano
- Abre GUI Python
- ¡A configurar! 🚀

---

## 📞 SI ALGO NO FUNCIONA

### "Arduino no responde"
```
Abre Monitor Serial → Baud 115200 → Envía "INFO"
Si no responde: Comprueba que serial_process() está en loop()
```

### "EEPROM no guarda"
```
Verifica que ejecutaste: EEPROM_SAVE
Revisa Monitor Serial para confirmar guardado
```

### "Postura no cambia"
```
1. Envía: STAND_COXA 0.5
2. Envía: STAND_HEIGHT 0.7
3. Presiona START en control remoto
La postura debe cambiar en vivo
```

---

¡**Éxito con tu Q-POD!** 🤖

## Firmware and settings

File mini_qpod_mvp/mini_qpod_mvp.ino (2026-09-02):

#include <Wire.h>
#include <Adafruit_PWMServoDriver.h>
#include <ctype.h>
#include <math.h>
#include <stdlib.h>
#include "robot_config.h"
#include "servo_control.h"
#include "gait_balance.h"

enum RobotMode : uint8_t { SAFE_OFF, CALIBRATION, STAND_MODE, LEG_TEST, WALK_MODE };
enum AbortCause : uint8_t { ABORT_NONE, ABORT_IMU_UNSAFE, ABORT_HOST_TIMEOUT };

Adafruit_PWMServoDriver pca(PCA9685_ADDRESS);
ServoController servos(pca);
ImuManager imu;
GaitBalance motion(servos, imu);

RobotMode mode = SAFE_OFF;
bool walkUnlocked = WALK_ENABLED_AT_BOOT;
int8_t selectedChannel = -1;
AbortCause abortCause = ABORT_NONE;
uint32_t lastCalibrationHostActivityMs = 0;
char inputLine[80];
uint8_t inputLength = 0;
constexpr uint8_t SONAR_PAN_CHANNEL = 12;
constexpr float SONAR_PAN_CENTER_DEG = 90.0f;
constexpr float SONAR_PAN_MIN_DEG = 67.5f;
constexpr float SONAR_PAN_MAX_DEG = 112.5f;

void printHelp();
void processCommand(char *line);
bool parseIntStrict(const char *text, int &value);
bool parseFloatStrict(const char *text, float &value);
bool calibrationImuSafe();
bool calibrationTiltSafe();
void abortToSafeOff(AbortCause cause);
const char *modeName(RobotMode value);
const char *abortName(AbortCause value);
void refreshCalibrationHostActivity();
bool calibrationHostTimedOut();

void setup() {
  pinMode(PIN_LED, OUTPUT);
  pinMode(PIN_BUZZER, OUTPUT);
  Serial.begin(115200);
  Wire.begin();
  pca.begin();
  pca.setPWMFreq(SERVO_PWM_HZ);
  delay(10);
  servos.begin();
  servos.disable();
  bool imuOk = imu.begin();
  Serial.println(F("\nMINI Q-POD MVP v0.3"));
  Serial.print(F("Enlace IMU Pico UART: "));
  Serial.println(IMU_ENABLED ? (imuOk ? F("ESPERANDO DATOS") : F("ERROR")) : F("DESACTIVADO"));
  Serial.println(F("Arranque seguro: servos OFF. Escriba HELP."));
}

void loop() {
  // La telemetria se mantiene aun en SAFE_OFF para comprobar la IMU sin PWM.
  if (IMU_ENABLED) imu.update();

  while (Serial.available()) {
    char c = Serial.read();
    if (c == '\r') continue;
    if (c == '\n') {
      inputLine[inputLength] = '\0';
      if (inputLength) processCommand(inputLine);
      inputLength = 0;
    } else if (inputLength < sizeof(inputLine) - 1) {
      inputLine[inputLength++] = c;
    }
  }

  if (mode == CALIBRATION && !calibrationImuSafe()) {
    abortToSafeOff(ABORT_IMU_UNSAFE);
  } else if (mode == CALIBRATION && calibrationHostTimedOut()) {
    abortToSafeOff(ABORT_HOST_TIMEOUT);
  } else if (mode == LEG_TEST || mode == WALK_MODE || mode == STAND_MODE) {
    if (!motion.update()) {
      abortToSafeOff(ABORT_IMU_UNSAFE);
    } else if (mode == LEG_TEST && motion.phase() == GaitBalance::IDLE) {
      mode = STAND_MODE;
      Serial.println(F("[LEG] Prueba terminada."));
    }
  }
  servos.update();
}

void processCommand(char *line) {
  char *cmd = strtok(line, " \t");
  if (!cmd) return;
  for (char *p = cmd; *p; ++p) *p = toupper((unsigned char)*p);

  if (!strcmp(cmd, "HELP")) {
    if (strtok(nullptr, " \t")) Serial.println(F("[ERR] HELP no recibe argumentos."));
    else printHelp();
  } else if (!strcmp(cmd, "OFF")) {
    if (strtok(nullptr, " \t")) { Serial.println(F("[ERR] OFF no recibe argumentos.")); return; }
    servos.disable();
    motion.stop();
    selectedChannel = -1;
    mode = SAFE_OFF;
    Serial.println(F("[OFF] ch=-1 PWM=OFF mode=SAFE_OFF"));
  } else if (!strcmp(cmd, "CALIB")) {
    if (strtok(nullptr, " \t")) { Serial.println(F("[ERR] CALIB no recibe argumentos.")); return; }
    if (!calibrationImuSafe()) { Serial.println(F("[ERR] CALIB bloqueado: IMU perdida o inclinacion insegura.")); return; }
    servos.disable();
    motion.stop();
    selectedChannel = -1;
    abortCause = ABORT_NONE;
    mode = CALIBRATION;
    refreshCalibrationHostActivity();
    Serial.println(F("[CALIB] ch=-1 PWM=OFF seleccione un canal con SELECT."));
  } else if (!strcmp(cmd, "SELECT")) {
    char *a = strtok(nullptr, " \t");
    int channel;
    if (!a || strtok(nullptr, " \t") || !parseIntStrict(a, channel) || channel < 0 || channel >= SERVO_COUNT) {
      Serial.println(F("[ERR] Uso: SELECT <0..12>.")); return;
    }
    if (mode != CALIBRATION) { Serial.println(F("[ERR] Use CALIB antes de SELECT.")); return; }
    servos.disable();
    selectedChannel = (int8_t)channel;
    refreshCalibrationHostActivity();
    Serial.print(F("[SELECT] ch=")); Serial.print(channel); Serial.println(F(" PWM=OFF"));
  } else if (!strcmp(cmd, "ENABLE")) {
    char *a = strtok(nullptr, " \t"), *b = strtok(nullptr, " \t");
    int channel; float requested, effective;
    if (!a || !b || strtok(nullptr, " \t") || !parseIntStrict(a, channel) ||
        !parseFloatStrict(b, requested) || channel < 0 || channel >= SERVO_COUNT) {
      Serial.println(F("[ERR] Uso: ENABLE <0..12> <angulo>.")); return;
    }
    if (mode != CALIBRATION || selectedChannel != channel) {
      Serial.println(F("[ERR] Seleccione primero ese canal con SELECT.")); return;
    }
    if (!calibrationImuSafe()) { Serial.println(F("[ERR] ENABLE bloqueado: IMU perdida o inclinacion insegura.")); return; }
    if (!servos.enableOnly((uint8_t)channel, requested, effective)) {
      Serial.println(F("[ERR] Canal no habilitable.")); return;
    }
    refreshCalibrationHostActivity();
    Serial.print(F("[ENABLE] ch=")); Serial.print(channel);
    Serial.print(F(" angle=")); Serial.println(effective, 2);
  } else if (!strcmp(cmd, "CENTER")) {
    char *a = strtok(nullptr, " \t"); int channel; float effective;
    if (!a || strtok(nullptr, " \t") || !parseIntStrict(a, channel) || channel < 0 || channel >= SERVO_COUNT) {
      Serial.println(F("[ERR] Uso: CENTER <0..12>.")); return;
    }
    if (mode != CALIBRATION || selectedChannel != channel || !servos.isOnlyChannelEnabled((uint8_t)channel)) {
      Serial.println(F("[ERR] CENTER exige canal seleccionado y habilitado.")); return;
    }
    if (!servos.setActiveTarget((uint8_t)channel, servos.center((uint8_t)channel), effective)) {
      Serial.println(F("[ERR] CENTER no aplicado.")); return;
    }
    refreshCalibrationHostActivity();
    Serial.print(F("[CENTER] ch=")); Serial.print(channel);
    Serial.print(F(" angle=")); Serial.println(effective, 2);
  } else if (!strcmp(cmd, "SERVO")) {
    char *a = strtok(nullptr, " \t"), *b = strtok(nullptr, " \t");
    int channel; float requested, effective;
    if (!a || !b || strtok(nullptr, " \t") || !parseIntStrict(a, channel) ||
        !parseFloatStrict(b, requested) || channel < 0 || channel >= SERVO_COUNT) {
      Serial.println(F("[ERR] Uso: SERVO <0..12> <angulo>.")); return;
    }
    if (mode != CALIBRATION || selectedChannel != channel || !servos.isOnlyChannelEnabled((uint8_t)channel)) {
      Serial.println(F("[ERR] SERVO exige canal seleccionado y habilitado.")); return;
    }
    if (!servos.setActiveTarget((uint8_t)channel, requested, effective)) {
      Serial.println(F("[ERR] Servo no aplicado.")); return;
    }
    refreshCalibrationHostActivity();
    Serial.print(F("[SERVO] ch=")); Serial.print(channel);
    Serial.print(F(" angle=")); Serial.println(effective, 2);
  } else if (!strcmp(cmd, "LIMITS")) {
    char *a = strtok(nullptr, " \t"), *b = strtok(nullptr, " \t");
    char *c = strtok(nullptr, " \t"), *d = strtok(nullptr, " \t");
    int channel, minAngle, centerAngle, maxAngle;
    if (!a || !b || !c || !d || strtok(nullptr, " \t") || !parseIntStrict(a, channel) ||
        !parseIntStrict(b, minAngle) || !parseIntStrict(c, centerAngle) || !parseIntStrict(d, maxAngle) ||
        channel < 0 || channel >= SERVO_COUNT) {
      Serial.println(F("[ERR] Uso: LIMITS <ch> <min> <center> <max>.")); return;
    }
    if (mode != CALIBRATION || servos.enabled()) {
      Serial.println(F("[ERR] LIMITS exige CALIB con PWM apagado.")); return;
    }
    if (!servos.setCalibration((uint8_t)channel, minAngle, centerAngle, maxAngle)) {
      Serial.println(F("[ERR] Limites incoherentes; no aplicados.")); return;
    }
    refreshCalibrationHostActivity();
    const ServoConfig &s = servos.config((uint8_t)channel);
    Serial.print(F("[LIMITS] ch=")); Serial.print(channel);
    Serial.print(F(" min=")); Serial.print(s.minAngle);
    Serial.print(F(" center=")); Serial.print(s.centerAngle);
    Serial.print(F(" max=")); Serial.print(s.maxAngle);
    Serial.print(F(" safeMin=")); Serial.print(servos.minSafe((uint8_t)channel), 0);
    Serial.print(F(" safeMax=")); Serial.println(servos.maxSafe((uint8_t)channel), 0);
  } else if (!strcmp(cmd, "SAVE")) {
    if (strtok(nullptr, " \t")) { Serial.println(F("[ERR] SAVE no recibe argumentos.")); return; }
    if (mode != SAFE_OFF) { Serial.println(F("[ERR] Ejecute OFF antes de SAVE.")); return; }
    Serial.println(servos.save() ? F("[SAVE] EEPROM OK.") : F("[ERR] Configuracion invalida."));
  } else if (!strcmp(cmd, "LOAD")) {
    if (strtok(nullptr, " \t")) { Serial.println(F("[ERR] LOAD no recibe argumentos.")); return; }
    if (mode != SAFE_OFF) { Serial.println(F("[ERR] Ejecute OFF antes de LOAD.")); return; }
    Serial.println(servos.load() ? F("[LOAD] EEPROM OK.") : F("[ERR] EEPROM invalida; sin cambios."));
  } else if (!strcmp(cmd, "DEFAULTS")) {
    if (mode != SAFE_OFF) Serial.println(F("[ERR] Ejecute OFF antes de DEFAULTS."));
    else if (strtok(nullptr, " \t")) Serial.println(F("[ERR] DEFAULTS no recibe argumentos."));
    else { servos.loadDefaults(); Serial.println(F("[DEFAULTS] En RAM; use CALIB para probar y SAVE para guardar.")); }
  } else if (!strcmp(cmd, "STAND")) {
    servos.enable(); motion.stand(); mode = STAND_MODE;
    Serial.println(F("[STAND] Moviendo lentamente a postura base."));
  } else if (!strcmp(cmd, "LEG")) {
    char *a = strtok(nullptr, " \t"); int leg;
    if (!a || strtok(nullptr, " \t") || !parseIntStrict(a, leg)) Serial.println(F("[ERR] Uso: LEG <0..3>."));
    else if (mode != STAND_MODE) Serial.println(F("[ERR] Primero STAND; uso LEG <0..3>."));
    else if (!motion.startLegTest((uint8_t)leg)) Serial.println(F("[ERR] Pata invalida u otro movimiento activo."));
    else { mode = LEG_TEST; Serial.println(F("[LEG] Prueba iniciada; listo para OFF.")); }
  } else if (!strcmp(cmd, "UNLOCK_WALK")) {
    if (strtok(nullptr, " \t")) Serial.println(F("[ERR] UNLOCK_WALK no recibe argumentos."));
    else { walkUnlocked = true; Serial.println(F("[WALK] Desbloqueado hasta reiniciar. Confirme que probo las 4 patas.")); }
  } else if (!strcmp(cmd, "WALK")) {
    if (strtok(nullptr, " \t")) Serial.println(F("[ERR] WALK no recibe argumentos."));
    else if (!walkUnlocked) Serial.println(F("[ERR] Use UNLOCK_WALK tras probar LEG 0..3."));
    else if (mode != STAND_MODE || !motion.startWalk()) Serial.println(F("[ERR] Primero STAND y espere estabilizacion."));
    else { mode = WALK_MODE; Serial.println(F("[WALK] Marcha lenta iniciada. OFF para detener.")); }
  } else if (!strcmp(cmd, "PING")) {
    if (strtok(nullptr, " \t")) { Serial.println(F("[ERR] PING no recibe argumentos.")); return; }
    refreshCalibrationHostActivity();
    Serial.print(F("PING mode=")); Serial.print(modeName(mode));
    Serial.print(F(" active=")); Serial.println(servos.activeChannel());
  } else if (!strcmp(cmd, "IMU")) {
    if (strtok(nullptr, " \t")) { Serial.println(F("[ERR] IMU no recibe argumentos.")); return; }
    Serial.print(F("IMU enabled=")); Serial.print(IMU_ENABLED);
    Serial.print(F(" healthy=")); Serial.print(imu.healthy());
    Serial.print(F(" roll=")); Serial.print(imu.roll(), 2);
    Serial.print(F(" pitch=")); Serial.print(imu.pitch(), 2);
    Serial.print(F(" calibrationTiltAbort=")); Serial.println(CALIBRATION_ABORT_ON_TILT);
  } else if (!strcmp(cmd, "SENSORS")) {
    if (strtok(nullptr, " \t")) { Serial.println(F("[ERR] SENSORS no recibe argumentos.")); return; }
    Serial.println(F("SENSORS relay=UART_PICO live=enabled"));
  } else if (!strcmp(cmd, "SONAR_ARM")) {
    if (strtok(nullptr, " \t")) { Serial.println(F("[ERR] SONAR_ARM no recibe argumentos.")); return; }
    if (mode != SAFE_OFF || !calibrationImuSafe()) { Serial.println(F("[ERR] SONAR_ARM exige SAFE_OFF e IMU segura.")); return; }
    servos.disable(); motion.stop(); selectedChannel = SONAR_PAN_CHANNEL;
    float effective;
    if (!servos.enableOnly(SONAR_PAN_CHANNEL, SONAR_PAN_CENTER_DEG, effective)) { selectedChannel = -1; Serial.println(F("[ERR] No se pudo habilitar CH12.")); return; }
    mode = CALIBRATION; abortCause = ABORT_NONE; refreshCalibrationHostActivity();
    Serial.print(F("[SONAR] ARM ch=12 angle=")); Serial.println(effective, 1);
  } else if (!strcmp(cmd, "SONAR")) {
    char *angleText = strtok(nullptr, " \t"); float requested, effective;
    if (!angleText || strtok(nullptr, " \t") || !parseFloatStrict(angleText, requested) || requested < SONAR_PAN_MIN_DEG || requested > SONAR_PAN_MAX_DEG) { Serial.println(F("[ERR] Uso: SONAR <67.5..112.5>.")); return; }
    if (mode != CALIBRATION || selectedChannel != SONAR_PAN_CHANNEL || !servos.isOnlyChannelEnabled(SONAR_PAN_CHANNEL)) { Serial.println(F("[ERR] Use SONAR_ARM antes de mover la cabeza.")); return; }
    if (!calibrationImuSafe() || !servos.setActiveTarget(SONAR_PAN_CHANNEL, requested, effective)) { abortToSafeOff(ABORT_IMU_UNSAFE); return; }
    refreshCalibrationHostActivity();
    Serial.print(F("[SONAR] angle=")); Serial.println(effective, 1);
  } else if (!strcmp(cmd, "SONAR_OFF")) {
    if (strtok(nullptr, " \t")) { Serial.println(F("[ERR] SONAR_OFF no recibe argumentos.")); return; }
    servos.disable(); motion.stop(); selectedChannel = -1; mode = SAFE_OFF;
    Serial.println(F("[SONAR] OFF PWM=OFF"));
  } else if (!strcmp(cmd, "SONAR_PING")) {
    if (mode == CALIBRATION && selectedChannel == SONAR_PAN_CHANNEL) refreshCalibrationHostActivity();
  } else if (!strcmp(cmd, "BEEP")) {
    char *frequencyText = strtok(nullptr, " \t"), *durationText = strtok(nullptr, " \t"); int frequency, duration;
    if (!frequencyText || !durationText || strtok(nullptr, " \t") || !parseIntStrict(frequencyText, frequency) || !parseIntStrict(durationText, duration) || frequency < 100 || frequency > 4000 || duration < 20 || duration > 1000) { Serial.println(F("[ERR] Uso: BEEP <100..4000 Hz> <20..1000 ms>.")); return; }
    tone(PIN_BUZZER, (unsigned int)frequency, (unsigned long)duration);
    Serial.print(F("[BEEP] frequency=")); Serial.print(frequency); Serial.print(F(" duration=")); Serial.println(duration);
  } else if (!strcmp(cmd, "STATUS")) {
    if (strtok(nullptr, " \t")) { Serial.println(F("[ERR] STATUS no recibe argumentos.")); return; }
    Serial.print(F("STATUS mode=")); Serial.print(modeName(mode));
    Serial.print(F(" servos=")); Serial.print(servos.enabled());
    Serial.print(F(" selected=")); Serial.print(selectedChannel);
    Serial.print(F(" active=")); Serial.print(servos.activeChannel());
    Serial.print(F(" imu=")); Serial.print(IMU_ENABLED ? imu.healthy() : true);
    Serial.print(F(" abort=")); Serial.print(abortName(abortCause));
    Serial.print(F(" phase=")); Serial.print((int)motion.phase());
    Serial.print(F(" leg=")); Serial.println(motion.activeLeg());
  } else if (!strcmp(cmd, "CONFIG")) {
    if (strtok(nullptr, " \t")) { Serial.println(F("[ERR] CONFIG no recibe argumentos.")); return; }
    Serial.print(F("CONFIG margin=")); Serial.println(servos.safetyMargin());
    for (uint8_t i = 0; i < SERVO_COUNT; ++i) {
      const ServoConfig &s = servos.config(i);
      Serial.print(F("CONFIG ch=")); Serial.print(i);
      Serial.print(F(" channel=")); Serial.print(s.channel);
      Serial.print(F(" min=")); Serial.print(s.minAngle);
      Serial.print(F(" center=")); Serial.print(s.centerAngle);
      Serial.print(F(" max=")); Serial.print(s.maxAngle);
      Serial.print(F(" direction=")); Serial.print(s.direction);
      Serial.print(F(" margin=")); Serial.print(servos.safetyMargin());
      Serial.print(F(" safeMin=")); Serial.print(servos.minSafe(i), 0);
      Serial.print(F(" safeMax=")); Serial.println(servos.maxSafe(i), 0);
    }
  } else {
    Serial.println(F("[ERR] Comando desconocido. Use HELP."));
  }
}

bool parseIntStrict(const char *text, int &value) {
  if (!text || !*text) return false;
  char *end = nullptr;
  long parsed = strtol(text, &end, 10);
  if (*end != '\0' || parsed < -32768L || parsed > 32767L) return false;
  value = (int)parsed;
  return true;
}

bool parseFloatStrict(const char *text, float &value) {
  if (!text || !*text) return false;
  const char *p = text;
  bool negative = false;
  if (*p == '+' || *p == '-') {
    negative = *p == '-';
    ++p;
  }
  bool hasDigits = false;
  float parsed = 0.0f;
  while (*p >= '0' && *p <= '9') {
    hasDigits = true;
    parsed = parsed * 10.0f + (*p - '0');
    if (!isfinite(parsed) || parsed > 1000000.0f) return false;
    ++p;
  }
  if (*p == '.') {
    ++p;
    float factor = 0.1f;
    while (*p >= '0' && *p <= '9') {
      hasDigits = true;
      parsed += (*p - '0') * factor;
      factor *= 0.1f;
      ++p;
    }
  }
  if (!hasDigits || *p != '\0' || !isfinite(parsed)) return false;
  value = negative ? -parsed : parsed;
  return true;
}

bool calibrationTiltSafe() {
  return !CALIBRATION_ABORT_ON_TILT ||
         (fabs(imu.roll()) <= DEFAULT_MAX_SAFE_TILT_DEG && fabs(imu.pitch()) <= DEFAULT_MAX_SAFE_TILT_DEG);
}

bool calibrationImuSafe() {
  return !IMU_ENABLED || (imu.healthy() && calibrationTiltSafe());
}

void refreshCalibrationHostActivity() {
  if (mode == CALIBRATION) lastCalibrationHostActivityMs = millis();
}

bool calibrationHostTimedOut() {
  return servos.activeChannel() >= 0 &&
         millis() - lastCalibrationHostActivityMs > CALIBRATION_HOST_TIMEOUT_MS;
}

void abortToSafeOff(AbortCause cause) {
  servos.disable();
  motion.stop();
  selectedChannel = -1;
  mode = SAFE_OFF;
  abortCause = cause;
  Serial.print(F("[ABORT] "));
  Serial.println(abortName(cause));
}

const char *modeName(RobotMode value) {
  switch (value) {
    case SAFE_OFF: return "SAFE_OFF";
    case CALIBRATION: return "CALIBRATION";
    case STAND_MODE: return "STAND_MODE";
    case LEG_TEST: return "LEG_TEST";
    case WALK_MODE: return "WALK_MODE";
    default: return "UNKNOWN";
  }
}

const char *abortName(AbortCause value) {
  switch (value) {
    case ABORT_NONE: return "NONE";
    case ABORT_IMU_UNSAFE: return "IMU_UNSAFE";
    case ABORT_HOST_TIMEOUT: return "HOST_TIMEOUT";
    default: return "UNKNOWN";
  }
}

void printHelp() {
  Serial.println(F("OFF | STATUS | CONFIG | IMU | SENSORS | PING | BEEP <Hz> <ms>"));
  Serial.println(F("SONAR_ARM | SONAR <67.5..112.5> | SONAR_OFF"));
  Serial.println(F("CALIB | SELECT <ch> | ENABLE <ch> <deg>"));
  Serial.println(F("CENTER <ch> | SERVO <ch> <deg> | LIMITS <ch> <min> <center> <max>"));
  Serial.println(F("SAVE | LOAD | DEFAULTS"));
  Serial.println(F("STAND | LEG <0..3> | UNLOCK_WALK | WALK"));
  Serial.println(F("Patas: 0=L1, 1=R1, 2=L2, 3=R2"));
}
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

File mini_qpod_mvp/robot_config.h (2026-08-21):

#pragma once

#include <Arduino.h>

// ============================================================
// MINI Q-POD MVP - UNICO ARCHIVO DE AJUSTE HABITUAL
// ============================================================

constexpr uint8_t SERVO_COUNT = 13;
constexpr uint8_t LEG_COUNT = 4;

constexpr uint8_t PCA9685_ADDRESS = 0x40;
constexpr float SERVO_PWM_HZ = 50.0f;
constexpr uint16_t SERVO_PULSE_MIN = 110;
constexpr uint16_t SERVO_PULSE_MAX = 510;

constexpr uint8_t PIN_LED = 5;
constexpr uint8_t PIN_BUZZER = 4;

// La MPU6050 pertenece a la Pico W. El Nano recibe la orientacion por UART.
// Cableado oficial: Pico GP4 (TX) -> Nano D2 (RX), GND comun.
constexpr bool IMU_ENABLED = true;
constexpr uint8_t IMU_UART_RX_PIN = 2;
// SoftwareSerial exige un TX, pero el MVP es unidireccional. D8 no se conecta.
// No usar D3 -> GP5 directamente: el Nano entrega 5 V y la Pico trabaja a 3.3 V.
constexpr uint8_t IMU_UART_UNUSED_TX_PIN = 8;
constexpr uint32_t IMU_UART_BAUD = 38400;
constexpr uint16_t IMU_PACKET_TIMEOUT_MS = 250;

struct ServoConfig {
  uint8_t channel;
  int16_t minAngle;
  int16_t centerAngle;
  int16_t maxAngle;
  int8_t direction;  // Reservado para la futura IK: +1 o -1.
  bool enabled;
};

// Valores iniciales tomados de default_config.json. Son provisionales:
// deben verificarse con el robot elevado antes de apoyar peso.
constexpr ServoConfig DEFAULT_SERVOS[SERVO_COUNT] = {
  { 0,  50,  90, 150,  1, true }, // L1_COXA
  { 1,  10,  95, 180,  1, true }, // L1_FEMUR
  { 2,   0, 100, 180, -1, true }, // L1_TIBIA
  { 3,  30,  90, 130,  1, true }, // R1_COXA
  { 4,   0,  90, 170, -1, true }, // R1_FEMUR
  { 5,   0,  90, 180, -1, true }, // R1_TIBIA
  { 6,  40,  90, 140,  1, true }, // L2_COXA
  { 7,  10, 100, 180,  1, true }, // L2_FEMUR
  { 8,   5, 100, 180, -1, true }, // L2_TIBIA
  { 9,  50,  90, 130, -1, true }, // R2_COXA
  {10,  15,  90, 180, -1, true }, // R2_FEMUR
  {11,   0,  90, 180, -1, true }, // R2_TIBIA
  {12,  45,  90, 135,  1, true }  // CUELLO
};

struct LegConfig {
  uint8_t coxa;
  uint8_t femur;
  uint8_t tibia;
};

constexpr LegConfig LEGS[LEG_COUNT] = {
  {0, 1, 2}, {3, 4, 5}, {6, 7, 8}, {9, 10, 11}
};

// Orden lento y cuasiestatico: L1, R2, R1, L2.
constexpr uint8_t GAIT_ORDER[LEG_COUNT] = {0, 3, 1, 2};

// Seguridad y movimiento.
constexpr uint8_t DEFAULT_SAFETY_MARGIN_DEG = 5;
constexpr float DEFAULT_MAX_SPEED_DEG_S = 35.0f;
constexpr uint16_t MOTION_UPDATE_MS = 20;

// Postura y marcha (ganancias 0..1 dentro del rango calibrado).
constexpr float DEFAULT_STAND_COXA_GAIN = 0.30f;
constexpr float DEFAULT_STAND_HEIGHT_GAIN = 0.60f;
constexpr float DEFAULT_STEP_GAIN = 0.20f;
constexpr float DEFAULT_LIFT_GAIN = 0.25f;
constexpr float DEFAULT_BODY_SHIFT_GAIN = 0.08f;

constexpr uint16_t DEFAULT_SHIFT_MS = 500;
constexpr uint16_t DEFAULT_LIFT_MS = 350;
constexpr uint16_t DEFAULT_SWING_MS = 450;
constexpr uint16_t DEFAULT_DROP_MS = 350;
constexpr uint16_t DEFAULT_SETTLE_MS = 400;

// Balance: correccion pequena y deliberadamente limitada.
constexpr float DEFAULT_MAX_SAFE_TILT_DEG = 12.0f;
constexpr float DEFAULT_BALANCE_KP = 0.35f;
constexpr float DEFAULT_MAX_BALANCE_CORRECTION_DEG = 4.0f;

// La calibracion se realiza con el robot elevado, pero conserva por defecto la
// misma proteccion de inclinacion que los modos de movimiento. Puede relajarse
// solo tras una validacion fisica explicita; perder la IMU siempre aborta.
constexpr bool CALIBRATION_ABORT_ON_TILT = true;
constexpr uint16_t CALIBRATION_HOST_TIMEOUT_MS = 1000;

// El usuario debe habilitar la marcha explicitamente despues de las pruebas.
constexpr bool WALK_ENABLED_AT_BOOT = false;

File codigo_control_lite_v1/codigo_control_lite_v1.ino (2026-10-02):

#include <Arduino.h>
#include <SPI.h>
#include <RF24.h>

// ================= NRF =================
RF24 radio(9, 10);                // CE, CSN
const uint8_t ADDR[6] = "JR001";  // Igual en RX

// ================= PINS CONTROL LITE =================
// Stick físico (lo tratamos como stick DERECHO)
static const uint8_t PIN_RX = A0;
static const uint8_t PIN_RY = A1;

// Click del stick (R3)
static const uint8_t PIN_R3 = 2;

// 4 botones “colores” del shield -> PS2
static const uint8_t PIN_TRIANGLE = 3;
static const uint8_t PIN_CIRCLE = 4;
static const uint8_t PIN_CROSS = 5;
static const uint8_t PIN_SQUARE = 6;

// Start / Select
static const uint8_t PIN_START = 7;
static const uint8_t PIN_SELECT = 8;

// Switch 3 posiciones (A2/A3 + GND)
static const uint8_t PIN_MODE_A = A2;
static const uint8_t PIN_MODE_B = A3;

// LED estado + buzzer pasivo
static const uint8_t PIN_LED_LINK = A4;  // resistencia 330–470 ohm
static const uint8_t PIN_BUZZER = A5;    // buzzer pasivo

// ================= AJUSTES =================
static const bool BUTTONS_ACTIVE_LOW = false;  // tu shield: suelto=0 presionado=1
static const uint8_t DEADZONE_PERCENT = 6;     // 4..10 típico
static const uint8_t FILTER_STRENGTH = 4;      // 2..8 (más alto = más suave)

static const uint16_t SEND_PERIOD_MS = 20;     // 50 Hz
static const uint16_t LQ_WINDOW_MS = 1000;     // link quality por ACK
static const uint16_t SERIAL_PERIOD_MS = 120;  // debug

// ================= PS2J v1 =================
enum PS2J_Button : uint16_t {
  PS2J_SELECT = (1u << 0),
  PS2J_START = (1u << 1),
  PS2J_SQUARE = (1u << 2),
  PS2J_CROSS = (1u << 3),
  PS2J_CIRCLE = (1u << 4),
  PS2J_TRIANGLE = (1u << 5),
  PS2J_R3 = (1u << 6),
};

struct PS2J_Packet {
  int8_t lx;      // Lite no tiene -> 0
  int8_t ly;      // Lite no tiene -> 0
  int8_t rx;      // tu stick X
  int8_t ry;      // tu stick Y
  uint16_t btn;   // 7 botones en bits
  uint8_t mode3;  // switch 0/1/2
  uint8_t seq;    // contador
  uint8_t flags;  // 1=Lite (opcional)
};
static_assert(sizeof(PS2J_Packet) == 9, "Control Lite PS2J v1 wire packet must be 9 bytes on AVR");

static const uint8_t PS2J_FLAG_LITE = 1;

// ================= INTERNALS =================
static int16_t filtX = 512, filtY = 512;

static uint32_t lastSendMs = 0, lastLQMs = 0, lastSerialMs = 0;
static uint16_t sent = 0, acked = 0;
static uint8_t lastLQ = 0;
static bool linkOk = false, prevLinkOk = false;

static uint32_t ledBlinkMs = 0;
static bool ledState = false;

static bool buzzerPlaying = false;
static uint32_t buzzerOffMs = 0;

static uint8_t seqCounter = 0;
static uint8_t prevMode = 255;

// ================= HELPERS =================
static inline bool pressed(uint8_t pin) {
  uint8_t v = digitalRead(pin);
  return BUTTONS_ACTIVE_LOW ? (v == LOW) : (v == HIGH);
}

static inline int16_t readFilteredAnalog(uint8_t pin, int16_t &accum) {
  int16_t raw = analogRead(pin);
  accum = accum + (raw - accum) / (int16_t)FILTER_STRENGTH;
  return accum;
}

static inline int8_t mapAxisToInt8(int16_t adc) {
  int16_t centered = adc - 512;
  int16_t dz = (int32_t)1023 * DEADZONE_PERCENT / 100 / 2;
  if (centered > -dz && centered < dz) centered = 0;

  int32_t scaled = (int32_t)centered * 127 / 512;
  if (scaled > 127) scaled = 127;
  if (scaled < -127) scaled = -127;
  return (int8_t)scaled;
}

static inline uint8_t readMode3pos() {
  // INPUT_PULLUP + centro del switch a GND:
  bool a = (digitalRead(PIN_MODE_A) == LOW);
  bool b = (digitalRead(PIN_MODE_B) == LOW);
  if (a && !b) return 0;
  if (!a && b) return 2;
  return 1;
}

static inline bool pressedR3() {
  return digitalRead(PIN_R3) == LOW;  // con INPUT_PULLUP, LOW = apretado
}

static uint16_t readButtonsPS2J() {
  uint16_t b = 0;
  if (pressed(PIN_SELECT)) b |= PS2J_SELECT;
  if (pressed(PIN_START)) b |= PS2J_START;
  if (pressed(PIN_SQUARE)) b |= PS2J_SQUARE;
  if (pressed(PIN_CROSS)) b |= PS2J_CROSS;
  if (pressed(PIN_CIRCLE)) b |= PS2J_CIRCLE;
  if (pressed(PIN_TRIANGLE)) b |= PS2J_TRIANGLE;


  if (pressedR3()) b |= PS2J_R3;  // <- SOLO R3 distinto
  //if (pressed(PIN_R3)) b |= PS2J_R3;
  return b;
}

// ---- buzzer pasivo ----
static void beep(uint16_t freq, uint16_t ms) {
  tone(PIN_BUZZER, freq);
  buzzerPlaying = true;
  buzzerOffMs = millis() + ms;
}

static void buzzerUpdate() {
  if (buzzerPlaying && (int32_t)(millis() - buzzerOffMs) >= 0) {
    noTone(PIN_BUZZER);
    buzzerPlaying = false;
  }
}

// ---- LED link real (ACK) ----
static void ledLinkUpdate(uint8_t lq, bool ok) {
  uint32_t now = millis();

  if (ok && lq >= 90) {  // link sólido
    digitalWrite(PIN_LED_LINK, HIGH);
    return;
  }

  uint16_t period = !ok ? 120 : (lq >= 70 ? 500 : (lq >= 40 ? 250 : 150));
  if (now - ledBlinkMs >= period) {
    ledBlinkMs = now;
    ledState = !ledState;
    digitalWrite(PIN_LED_LINK, ledState ? HIGH : LOW);
  }
}

void setup() {
  Serial.begin(115200);

  // Botones (ACTIVE HIGH)
  pinMode(PIN_R3, INPUT_PULLUP);
  pinMode(PIN_TRIANGLE, INPUT);
  pinMode(PIN_CIRCLE, INPUT);
  pinMode(PIN_CROSS, INPUT);
  pinMode(PIN_SQUARE, INPUT);
  pinMode(PIN_START, INPUT);
  pinMode(PIN_SELECT, INPUT);

  // Switch
  pinMode(PIN_MODE_A, INPUT_PULLUP);
  pinMode(PIN_MODE_B, INPUT_PULLUP);

  // LED + buzzer
  pinMode(PIN_LED_LINK, OUTPUT);
  pinMode(PIN_BUZZER, OUTPUT);
  digitalWrite(PIN_LED_LINK, LOW);
  noTone(PIN_BUZZER);

  // Filtros
  filtX = analogRead(PIN_RX);
  filtY = analogRead(PIN_RY);

  // NRF
  radio.begin();
  radio.setChannel(76);
  radio.setDataRate(RF24_250KBPS);
  radio.setPALevel(RF24_PA_LOW);
  radio.setRetries(5, 10);
  radio.openWritingPipe(ADDR);
  radio.stopListening();

  beep(1800, 80);
  Serial.println(F("=== CONTROL LITE TX PS2J v1 ==="));
}
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

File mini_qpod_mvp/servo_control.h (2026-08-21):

#pragma once

#include <Arduino.h>
#include <Adafruit_PWMServoDriver.h>
#include <EEPROM.h>
#include "robot_config.h"

class ServoController {
 public:
  struct StoredConfig {
    uint16_t magic;
    uint8_t version;
    uint8_t safetyMarginDeg;
    ServoConfig servos[SERVO_COUNT];
    uint16_t checksum;
  };

  static constexpr uint16_t STORAGE_MAGIC = 0x514D; // "QM"
  static constexpr uint8_t STORAGE_VERSION = 1;
  static constexpr int8_t NO_ACTIVE_CHANNEL = -1;

  explicit ServoController(Adafruit_PWMServoDriver &driver) : pca_(driver) {}

  void begin() {
    loadDefaults();
    load();
    for (uint8_t i = 0; i < SERVO_COUNT; ++i) {
      current_[i] = config_.servos[i].centerAngle;
      target_[i] = current_[i];
    }
    lastUpdateMs_ = millis();
  }

  void loadDefaults() {
    config_.magic = STORAGE_MAGIC;
    config_.version = STORAGE_VERSION;
    config_.safetyMarginDeg = DEFAULT_SAFETY_MARGIN_DEG;
    for (uint8_t i = 0; i < SERVO_COUNT; ++i) config_.servos[i] = DEFAULT_SERVOS[i];
    config_.checksum = calculateChecksum(config_);
  }

  bool validate() const {
    if (config_.magic != STORAGE_MAGIC || config_.version != STORAGE_VERSION) return false;
    if (config_.safetyMarginDeg > 20) return false;
    for (uint8_t i = 0; i < SERVO_COUNT; ++i) {
      const ServoConfig &s = config_.servos[i];
      if (s.channel > 15 || s.minAngle < 0 || s.maxAngle > 180) return false;
      if (!(s.minAngle < s.centerAngle && s.centerAngle < s.maxAngle)) return false;
      if (s.direction != 1 && s.direction != -1) return false;
      if ((s.maxAngle - s.minAngle) <= (2 * config_.safetyMarginDeg)) return false;
    }
    return true;
  }

  bool save() {
    if (!validate()) return false;
    config_.checksum = calculateChecksum(config_);
    EEPROM.put(0, config_);
    return true;
  }

  bool load() {
    StoredConfig candidate;
    EEPROM.get(0, candidate);
    if (candidate.magic != STORAGE_MAGIC || candidate.version != STORAGE_VERSION) return false;
    if (candidate.checksum != calculateChecksum(candidate)) return false;
    StoredConfig old = config_;
    config_ = candidate;
    if (!validate()) {
      config_ = old;
      return false;
    }
    return true;
  }

  bool setCalibration(uint8_t index, int minAngle, int centerAngle, int maxAngle) {
    if (index >= SERVO_COUNT) return false;
    ServoConfig old = config_.servos[index];
    config_.servos[index].minAngle = minAngle;
    config_.servos[index].centerAngle = centerAngle;
    config_.servos[index].maxAngle = maxAngle;
    if (!validate()) {
      config_.servos[index] = old;
      return false;
    }
    return true;
  }

  bool setTarget(uint8_t index, float angle) {
    if (index >= SERVO_COUNT || !config_.servos[index].enabled) return false;
    target_[index] = clampSafe(index, angle);
    return true;
  }

  void setAllCenters() {
    for (uint8_t i = 0; i < SERVO_COUNT; ++i) setTarget(i, center(i));
  }

  void enable() {
    enabled_ = true;
    activeChannel_ = NO_ACTIVE_CHANNEL;
    lastUpdateMs_ = millis();
  }

  void disable() {
    enabled_ = false;
    activeChannel_ = NO_ACTIVE_CHANNEL;
    for (uint8_t i = 0; i < SERVO_COUNT; ++i) pca_.setPWM(config_.servos[i].channel, 0, 0);
  }
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

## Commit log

2026-08-15 Versión inicial funcional de Mini Q-Pod
    [Assembly1.0001.iam, Assembly1.iam, Assembly2.0004.iam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]
2026-08-21 feat: add safe Mini Q-POD servo calibrator
2026-08-21 feat: add active calibration backup gate
2026-09-02 feat: add Pico sensor relay and safe sonar control
2026-09-02 fix: remove unavailable sonar servo dependency
    [mini_qpod_mvp.ino]
2026-09-02 fix: compile Nano sensor station relay
    [gait_balance.h, mini_qpod_mvp.ino]
2026-09-22 feat: add ESP32-CAM primitive vision stage 1
2026-09-23 feat: add safe Nano servo mapping firmware
2026-09-23 feat: add safe servo mapping console
2026-09-23 fix: pace console after Nano startup
    [console.py, stability_test.py, test_console.py]
2026-10-02 docs: keep ESP32-CAM device backup out of public repo
2026-10-02 docs: formalize Mini Q-POD stage two roadmap
2026-10-02 docs: select Pico W for future locomotion
2026-10-02 feat: add Pico W locomotion firmware
2026-10-02 docs: identify Pico WH and reserve S3 UART
